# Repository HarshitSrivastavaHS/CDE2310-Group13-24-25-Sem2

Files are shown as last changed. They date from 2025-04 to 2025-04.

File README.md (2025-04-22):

# Autonomous Thermal Search and Rescue Robot

This project presents a custom-built autonomous ground robot designed to simulate a post-earthquake search and rescue scenario. The robot explores an unknown environment using SLAM, identifies potential human survivors based on heat signatures, and marks their locations by deploying a visual flare mechanism (ping pong ball shooter).

The system was developed on the TurtleBot3 Burger platform, integrating mechanical actuation, custom electronics, and a complete ROS2-based navigation and sensing software stack.

---

## 🧩 System Overview

The robot autonomously locates **two heat sources**, simulating trapped humans, and activates a mechanical actuator to launch a flare at each source. It avoids revisiting previously detected targets and explores until both are found.

---

## 🛠 Mechanical Subsystem

A custom **cam-cantilever-spring mechanism** forms the core of the actuator, which launches a ping pong ball upon confirmation of a heat source.

- **Mechanism**: Surface cam, spring-loaded lever, and firing frame  
- **Stroke**: 14 mm  
- **Actuation**: Driven by a motor with gearbox

🔗 Refer to the [`Mechanical/`](./Mechanical/) directory for design files and CAD models.

---

## ⚡ Electrical Subsystem

The electrical architecture is built around a **custom-designed PCB** mounted on the Raspberry Pi, ensuring robust connectivity and easier integration of power and signal lines.

- **Power Supply**: PCB powered via OpenCR 5V output  
- **Components**: Connects thermal sensor, motor driver (L298N), and GPIO-controlled MOSFET  
- **Testing**: JLCPCB performed electrical tests; assembly and validation were done at E2 Electronics Lab  
- **Note**: GPIO pin 24 was intentionally left unused due to a layout issue

📁 All schematics, BOMs, and datasheets are available in the [`Electrical/`](./Electrical/) folder.

---

## 💻 Software Subsystem

The software is implemented using **ROS2 Humble**, running on a Raspberry Pi. It integrates exploration, navigation, thermal detection, and actuator control.

**Key components**:

- **SLAM**: Real-time mapping using `slam_toolbox`  
- **Exploration**: Custom ROS2 node interfacing with the Nav2 stack  
- **Heat Source Detection**: AMG8833 thermal sensor, processed with thresholding  
- **Flare Deployment**: GPIO control of actuator once source is confirmed

📂 Full implementation, test scripts, and configuration are located in the [`Software/`](./Software/) directory.

---

## 👥 Team

- Srivastava Harshit
- Wong Jian Bin
- Singh Siddhant Narayan
- Pranav Vangal Swaminathan
- Ni Hang, Alex

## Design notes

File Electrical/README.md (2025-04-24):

# Electrical

## System Schematics


## the onboard raspberry pi PCB
- To facilitate better wiring and stability of electrical system, the pcb is designed with great help from Mr. Eugene.

### Schematics


#### Bill of material
The bill of material can be found at
<p>
<table>
<tr><td><b>Qty</b></td><td><b>Value</b></td><td><b>Device</b></td><td><b>Footprint Name</b></td><td><b>Parts</b></td><td><b>Detailed Description</b></td><td><b>CATEGORY</b></td><td><b>CREATED_BY</b></td><td><b>DATASHEET</b></td><td><b>DESCRIPTION</b></td><td><b>DIGIKEY_PART_NUMBER</b></td><td><b>DIGI_KEY_PART_NUMBER</b></td><td><b>DRAIN_CURRENT</b></td><td><b>IC_MAX</b></td><td><b>MANUFACTURER</b></td><td><b>MPN</b></td><td><b>OPERATING_TEMPERATURE</b></td><td><b>PACKAGE_SIZE</b></td><td><b>PACKAGE_TYPE</b></td><td><b>PART_STATUS</b></td><td><b>PITCH</b></td><td><b>POPULARITY</b></td><td><b>ROHS</b></td><td><b>SERIES</b></td><td><b>SUBCATEGORY</b></td><td><b>TEMPERATURE_COEFFICIENT</b></td><td><b>THERMALLOSS</b></td><td><b>TOLERANCE</b></td><td><b>TYPE</b></td><td><b>VCEO_MAX</b></td></tr>
<tr><td>2</td><td>10k</td><td>R_AXIAL-7.2MM-PITCH</td><td>RESAD724W46L381D178B</td><td>R6, R8</td><td>Resistor Fixed - Generic</td><td>Resistors</td><td></td><td></td><td>Axial Resistor 7.24 mm pitch 3.81 mm body length 1.78 mm body diameter</td><td></td><td></td><td></td><td></td><td></td><td></td><td></td><td>AXIAL</td><td>THT</td><td></td><td></td><td></td><td></td><td></td><td></td><td></td><td></td><td></td><td></td><td></td></tr>
<tr><td>2</td><td>1N4148DO35-10</td><td>1N4148DO35-10</td><td>DO35-10</td><td>D3, D4</td><td>DIODE</td><td></td><td></td><td></td><td></td><td></td><td></td><td></td><td></td><td></td><td></td><td></td><td></td><td></td><td></td><td></td><td>21</td><td></td><td></td><td></td><td></td><td></td><td></td><td></td><td></td></tr>
<tr><td>2</td><td>1k</td><td>R_AXIAL-7.2MM-PITCH</td><td>RESAD724W46L381D178B</td><td>R5, R7</td><td>Resistor Fixed - Generic</td><td>Resistors</td><td></td><td></td><td>Axial Resistor 7.24 mm pitch 3.81 mm body length 1.78 mm body diameter</td><td></td><td></td><td></td><td></td><td></td><td></td><td></td><td>AXIAL</td><td>THT</td><td></td><td></td><td></td><td></td><td></td><td></td><td></td><td></td><td></td><td></td><td></td></tr>
<tr><td>1</td><td>2828XX-4282834-4</td><td>2828XX-4282834-4</td><td>TERMBLK_254-4N</td><td>5V,12VTERBLK</td><td>4 Position Wire to Board Terminal Block Horizontal with Board</td><td>Fixed Terminal Blocks</td><td></td><td>https://www.te.com/usa-en/product-282834-4.datasheet.pdf</td><td>4 Position Wire to Board Terminal Block Horizontal with Board 0.100" (2.54mm) Through Hole</td><td></td><td></td><td></td><td></td><td>TE Connectivity AMP Connectors</td><td>282834-4</td><td>-40�C ~ 105�C</td><td>NA</td><td>THT</td><td>ACTIVE</td><td>0.100" (2.54mm) </td><td></td><td>COMPLIANT</td><td>Buchanan</td><td>Terminal Blocks</td><td></td><td></td><td></td><td>Through Hole Screw - Rising Cage Clamp Side wire entry Horizontal with Board</td><td></td></tr>
<tr><td>2</td><td>61300211121</td><td>61300211121</td><td>61300211121</td><td>5VSOLENOID, 12VSOLENOID</td><td>CONN HEADER VERT 2POS 2.54MM</td><td></td><td>PCBLayout.com</td><td></td><td></td><td></td><td>732-5315-ND</td><td></td><td></td><td>Wurth Electronics Inc.</td><td>61300211121</td><td></td><td></td><td></td><td></td><td></td><td></td><td></td><td></td><td></td><td></td><td></td><td></td><td></td><td></td></tr>
<tr><td>1</td><td>61300311121</td><td>61300311121</td><td>61300311121</td><td>SERVO</td><td>CONN HEADER VERT 3POS 2.54MM</td><td></td><td>PCBLayout.com</td><td></td><td></td><td></td><td>732-5316-ND</td><td></td><td></td><td>Wurth Electronics Inc.</td><td>61300311121</td><td></td><td></td><td></td><td></td><td></td><td></td><td></td><td></td><td></td><td></td><td></td><td></td><td></td><td></td></tr>
<tr><td>1</td><td>61300511121</td><td>61300511121</td><td>61300511121</td><td>AMG8833</td><td>CONN HEADER VERT 5POS 2.54MM</td><td></td><td>PCBLayout.com</td><td></td><td></td><td></td><td>732-5318-ND</td><td></td><td></td><td>Wurth Electronics Inc.</td><td>61300511121</td><td></td><td></td><td></td><td></td><td></td><td></td><td></td><td></td><td></td><td></td><td></td><td></td><td></td><td></td></tr>
<tr><td>2</td><td>61302011121</td><td>61302011121</td><td>61302011121</td><td>GPIO_EVEN, GPIO_ODD</td><td>CONN HEADER VERT 20POS 2.54MM</td><td></td><td>PCBLayout.com</td><td></td><td></td><td>732-5329-ND</td><td></td><td></td><td></td><td>Wurth Electronics Inc.</td><td>61302011121</td><td></td><td></td><td></td><td></td><td></td><td></td><td></td><td></td><td></td><td></td><td></td><td></td><td></td><td></td></tr>
<tr><td>2</td><td>NMOSFET_TO220</td><td>NMOSFET_TO220</td><td>TO220BV</td><td>Q1, Q2</td><td>N-Channel MOSFET - Generic</td><td>Transistor</td><td></td><td>https://www.diodes.com/assets/Package-Files/TO220-3.pdf</td><td>Generic N Channel MOSFET TO220 Package Through Hole</td><td></td><td></td><td></td><td></td><td></td><td></td><td></td><td>TO220</td><td>THT</td><td></td><td></td><td></td><td></td><td></td><td>MOSFET</td><td></td><td></td><td></td><td>N-Channel</td><td></td></tr>
<tr><td>1</td><td>PINHD-1X2/90</td><td>PINHD-1X2/90</td><td>1X02/90</td><td>JP1</td><td>PIN HEADER</td><td>Headers</td><td></td><td></td><td>Header-Right Angle-2 Position</td><td></td><td></td><td></td><td></td><td></td><td></td><td></td><td></td><td>THT</td><td></td><td>0.100" (2.54mm)</td><td></td><td></td><td></td><td>Headers-Male Pins</td><td></td><td></td><td></td><td>Board to Board or Cable-Unshrouded-Through Hole-Right Angle</td><td></td></tr>
</table>

- Depending on the use case, one may need an extra female 2x20 1.64mm header to act as a connector to Raspberry Pi.

### 3D Model


>[!Note]
>The gerber files can be found at PCB schematic v36_2025-03-21.zip



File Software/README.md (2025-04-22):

# 🧠 Software 

This directory contains all software components used in the robot that autonomously explores an environment, detects thermal heat signatures (simulating trapped humans), and fires a flare to mark the location.

The software runs on **Ubuntu 22.04 (64-bit)** with **ROS2 Humble**, deployed on a **Raspberry Pi 4 (4GB RAM)**.

---

## For more details about a node, kindly go to:
- [`Explorer and Firing/`](./workspace/src/Autonomous-Explorer-and-Mapper-ros2-nav2/)
- [`Thermal/`](./workspace/src/cde2310/)

---

## ⚙️ Setup Instructions

These steps will help you replicate the software environment on a fresh Raspberry Pi setup.

### 1. Clone the Repository

```
git clone https://github.com/<your-username>/CDE2310-Group13-24-25-Sem2.git
cd CDE2310-Group13-24-25-Sem2/Software
```

### 2. Install ROS2 Humble

Follow the official guide for ROS2 Humble on Ubuntu 22.04:  
https://docs.ros.org/en/humble/Installation/Ubuntu-Install-Debians.html

After installing, add ROS to your shell:

```
echo "source /opt/ros/humble/setup.bash" >> ~/.bashrc
source ~/.bashrc
```

### 3. Install Required Libraries

You’ll need the following Python libraries on the Raspberry Pi:

```
pip install adafruit-circuitpython-amg88xx
pip install numpy
```

Also make sure `RPi.GPIO` is available (comes preinstalled on most RPi OSes):

```
sudo apt install python3-rpi.gpio
```

Make sure the following ROS2 packages are installed:

```
sudo apt install ros-humble-navigation2
sudo apt install ros-humble-slam-toolbox
```

### 4. Build the ROS2 Workspace

```
cd workspace
rosdep install --from-paths src --ignore-src -r -y
colcon build
source install/setup.bash
```

---

## 🧪 Nodes Overview

- **thermal.py**  
  Detects heat sources using the AMG8833 sensor and publishes direction commands (`L`, `R`, `F<number>`, `S`) on `/thermal_direction`.

- **explorer.py**  
  Custom frontier-based exploration node. Uses SLAM map to detect unexplored frontiers and plans paths using Nav2 + Dijkstra. Listens to `/thermal` to decide when to stop and fire. Also controls the GPIO pins on the Raspberry Pi to trigger the firing mechanism (flare shooter).

All nodes are written in Python using the `rclpy` client library and structured as standalone ROS2 nodes.

---

## 📂 Folder Structure

- `workspace/` — ROS2 workspace (nodes live in `src/`)
- `test` — Some Test files written during development and testing.
- `images` — Some static image files for the readme

---

## 🧷 Useful Aliases

You can set up these in your `~/.bashrc` to make launching components easier:

```
alias config="cd ~/CDE2310-Group13-24-25-Sem2/Software/workspace/src/cde2310/config"
alias nav2="config && ros2 launch nav2_bringup navigation_launch.py params_file:=./nav2_params.yaml"
alias slam="ros2 launch slam_toolbox online_async_launch.py"
alias thermal="ros2 run cde2310 thermal"
alias explore="ros2 run custom_explorer explorer"
```

---

## 🧯 System Behavior

1. Robot starts SLAM and begins exploring via the `explorer` node.
2. On detecting a heat signature, `thermal` node sends direction codes to `explorer`.
3. `explorer` aligns the robot toward the heat and moves forward until detection is maximized.
4. When the heat is confirmed (`S`), it triggers the launcher using GPIO and marks the location.
5. It then resumes exploration and ignores previously visited heat spots.

---

## 🛠 Testing Notes

Each module was individually tested and passed. However, due to time constraints, final integrated behavior had issues:

- The robot froze during continuous navigation updates when multiple `/thermal_direction` messages were received.
- Arbitration logic between thermal and exploration was insufficient.
- Final demo attempt failed due to lack of smooth integration (our bad 😔).

Future improvements would include using a centralized state machine or ROS2 behavior trees to manage transitions between exploring, detecting, aligning, and firing.

---

## RQT Graph of the setup

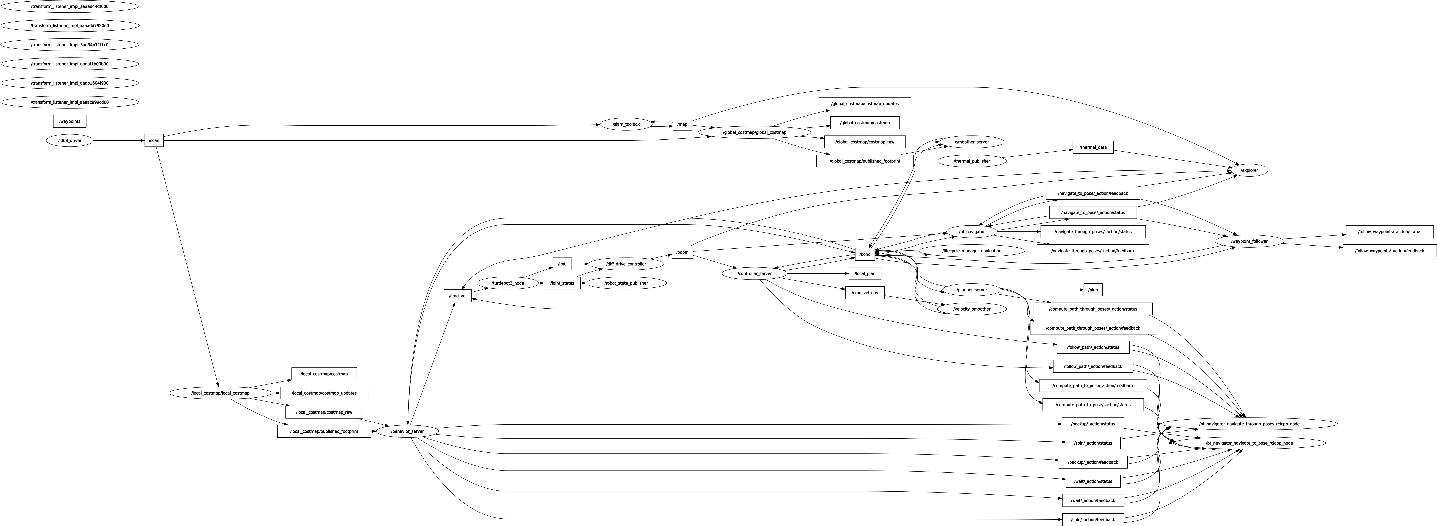
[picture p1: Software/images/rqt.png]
RQT


---

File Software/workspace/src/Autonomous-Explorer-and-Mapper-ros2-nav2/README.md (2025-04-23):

**Explorer Node Overview**

This code implements a ROS2 (Robot Operating System) node that enables a robot to autonomously explore its environment using a thermal sensor (simulated here) and navigate based on detected heat sources. It subscribes to various topics such as the map, odometry, and thermal sensor data, and publishes commands to control the robot's movement.

**Key Functionalities:**

1. **Map and Odometry Handling:**
    - Subscribes to /map for the robot’s environment map (OccupancyGrid).
    - Subscribes to /odom for the robot's current position and orientation (Odometry).
2. **Thermal Sensor Integration:**
    - Subscribes to /thermal_data for thermal sensor readings.
    - Identifies heat sources and makes decisions based on their locations.
3. **Autonomous Navigation:**
    - Uses an action client (NavigateToPose) to navigate to specific positions.
    - Based on thermal data, the robot moves towards detected heat sources, avoids revisiting them, and can perform specific tasks like firing a projectile at heat sources.

**Important Methods:**

**1\. map_callback(msg)**

- **Purpose:** This method receives the environment map (OccupancyGrid) and stores it in the map_data attribute. The map is used later for navigation and exploration.

**2\. odom_callback(msg)**

- **Purpose:** This method processes the robot's position and orientation (odometry data). It extracts the robot's current coordinates and orientation (in radians) using a quaternion-to-Euler conversion.

**3\. thermal_callback(msg)**

- **Purpose:** Receives thermal data from the thermal sensor. The sensor data would be used to identify the location of heat sources. 

**4\. check_heat_source()**

- **Purpose:** This method is periodically triggered by a timer. It checks if a heat source has been detected:
  - If no heat source is detected, it calls self.explore() to continue searching.
  - If a heat source is found, it evaluates the type of action needed based on the heat source's characteristics (e.g., move forward, turn, or fire a projectile).

**5\. startFiring()**

- **Purpose:** This function controls a PWM pin on a Raspberry Pi to simulate firing a flare (a ping pong ball) when a heat source is detected. The firing time is controlled by the PWM_PIN and DUTY_CYCLE parameters.

**6\. move_forward(pixels)**

- **Purpose:** This function computes the target coordinates (target_x, target_y) based on the current robot position and the desired forward distance (calculated from thermal data). It then sends a navigation goal to move the robot towards those coordinates using the NavigateToPose action.

**7\. turn_left_in_place() and turn_right_in_place()**

- **Purpose:** These methods control the robot’s in-place rotation using the cmd_vel topic. The robot turns a specified number of degrees (default 10°) either to the left or right by publishing angular velocity commands.

**Other Key Features:**

- **PWM Control for Firing Mechanism:** The startFiring method demonstrates controlling a firing mechanism via PWM on the Raspberry Pi's GPIO pin. This action is triggered when a specific type of heat source is detected.
- **Exploration and Heat Source Handling:** The robot follows basic rules for detecting and responding to heat sources:
  - If the heat source is a "L" (left turn), it will turn left.
  - If it's "R" (right turn), the robot turns right.
  - If it's "F" (forward), the robot moves forward towards the heat source if it hasn't already visited it.
  - If the heat source is "S" (fire), it activates the firing mechanism.

**Navigation Control:**

- The NavigateToPose action client is used to send movement goals to the robot, either for exploration or for specific heat source targets. These navigation goals are based on the robot’s current position and orientation.

**Dependencies:**

- **ROS2**: This node uses ROS2 for handling topics, actions, and messages (nav_msgs, geometry_msgs, std_msgs, etc.).
- **RPi.GPIO**: For controlling the Raspberry Pi's GPIO pins to manage the firing mechanism.
- **NumPy**: For handling thermal data as arrays.
- **tf_transformations**: For converting quaternion-based orientation data to Euler angles (and vice versa).

---

### The frontier based exploration is forked from a different repo. Credits to the original owner: [AniArka - Autonomous Explorer and Mapper Ros2 Nav2](https://github.com/AniArka/Autonomous-Explorer-and-Mapper-ros2-nav2)

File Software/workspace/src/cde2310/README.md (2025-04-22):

# ThermalPublisher Node

This is a ROS 2 Python node that reads data from the AMG8833 8x8 thermal sensor and publishes directional information based on detected heat patterns.

## Overview

The node captures thermal data and analyzes it to determine the direction of the heat source relative to the sensor. It then publishes a corresponding string message to the `thermal_data` topic.

## Published Topic

- **/thermal_data** (`std_msgs/String`): Contains direction info:
  - `N` – No significant heat source detected
  - `S` – Most pixels are above the threshold (saturation)
  - `L` – Heat is primarily on the left side
  - `R` – Heat is primarily on the right side
  - `F{n}` – Heat is centered; `{n}` indicates number of hot pixels in the center

## How It Works

1. The node initializes the AMG8833 sensor using I2C.
2. It captures thermal data every second.
3. On the **first frame**, the ambient temperature is calculated and saved.
4. In subsequent frames, a dynamic threshold (`ambient + 2.5°C`) is used to identify "hot" pixels.
5. Based on the distribution of hot pixels:
   - If fewer than 5% are hot → `N`
   - If more than 50% are hot → `S`
   - Otherwise, direction (`L`, `R`, `F`) is determined by location of hot spots.

## Dependencies

- ROS 2 (Foxy/Humble or later)
- `adafruit-circuitpython-amg88xx`
- `rclpy`
- `board`
- `busio`
- `std_msgs`

Install the sensor library using pip:
```
pip install adafruit-circuitpython-amg88xx
```

## Running the Node

Make sure your I2C sensor is connected and enabled, then run:
```
thermal
```

> [!CAUTION]
> This assumes you have added an alias by following the instructions [here](../../../README.md).

> [!NOTE]
> Make sure I2C is enabled on your board (e.g., Raspberry Pi).
> The first frame is used to calibrate the ambient temperature.
> If the node starts too close to a heat source, it may skew initial ambient detection.

## Custom parameter file for Nav2 Stack

The custom parameter file for Nav2 Stack is in the config folder.
The file has custom parameters for robot radius, adjusted costmaps settings and other parameters for smoother mission.

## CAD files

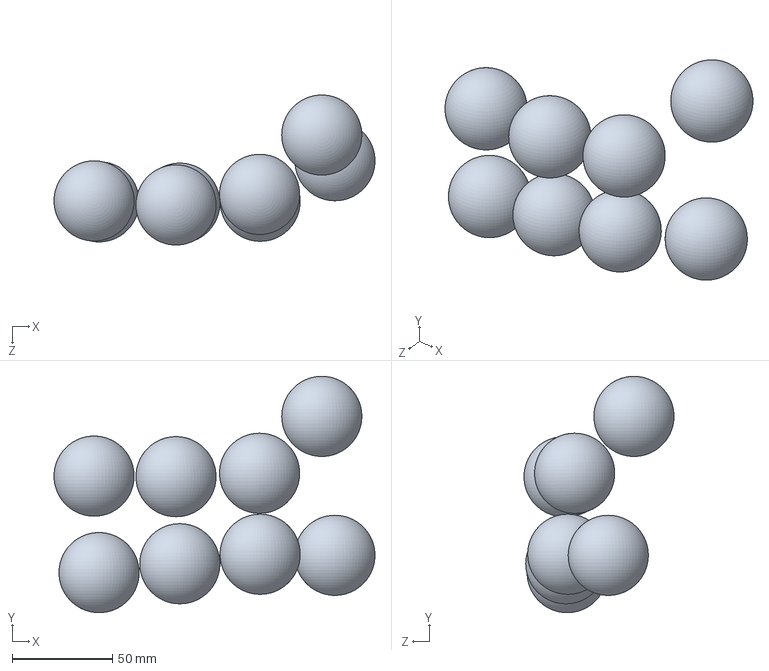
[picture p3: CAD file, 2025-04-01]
Mechanical/Hopper_test.SLDASM
160.2 x 118.0 x 74.9 mm
PingPongBall x 8

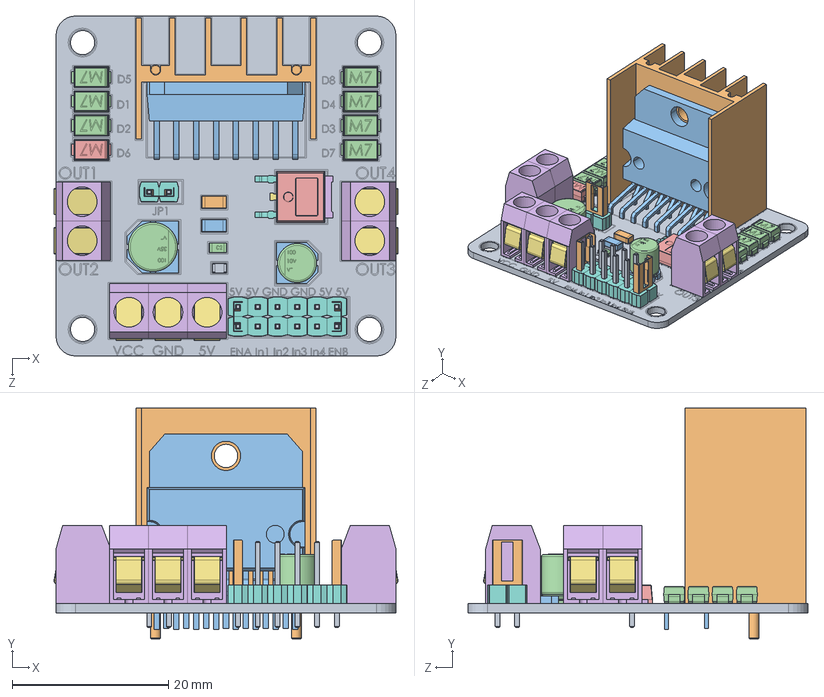
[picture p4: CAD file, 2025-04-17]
Mechanical/Hopper/L298N Motor Driver/L298N Driver.SLDASM
44.0 x 29.5 x 43.5 mm
Board
L298N Heat Sink
L298N
M7 Chip Diode x 7
D5
Left Out Connector x 7
Wire Tension Clip x 7
Spacer x 14
Male Header Pin x 14
Metal Insert x 3
Plastic Base x 2
Cap Body x 2
TO-252_body.stp
TO-252_heatsink_2.stp
TO-252_pin_short.stp
TO-252_pin_standart.stp x 2
LED
Cap 2
Cap 1
Resistor

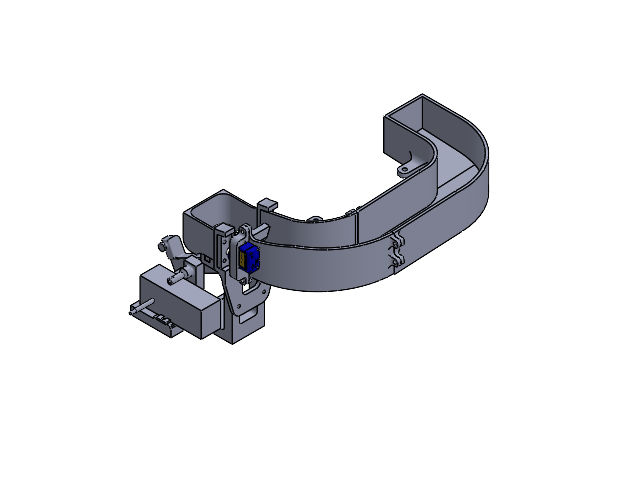
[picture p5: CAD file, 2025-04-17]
Mechanical/Hopper/Hopper_launcher_Assem.SLDASM
mount
cam
lever
pin
Motor
cone_holder
funnel_base
body_v2
pin_funnel
Launcher_mount
Hopper_v2_part1
Hopper_v2_part2

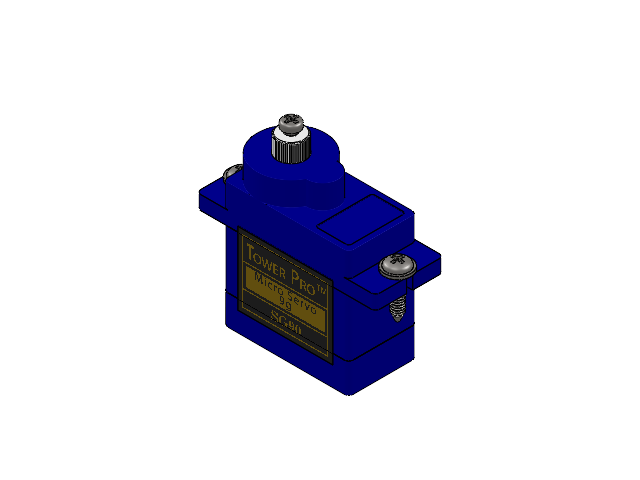
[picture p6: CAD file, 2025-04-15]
Mechanical/Hopper/Micro Servo/SG90 - Micro Servo 9g - Tower Pro.SLDASM
SG90 - Micro Servo 9g - Tower Pro.1
SG90 - Micro Servo 9g - Tower Pro.5 x 2
SG90 - Micro Servo 9g - Tower Pro.6

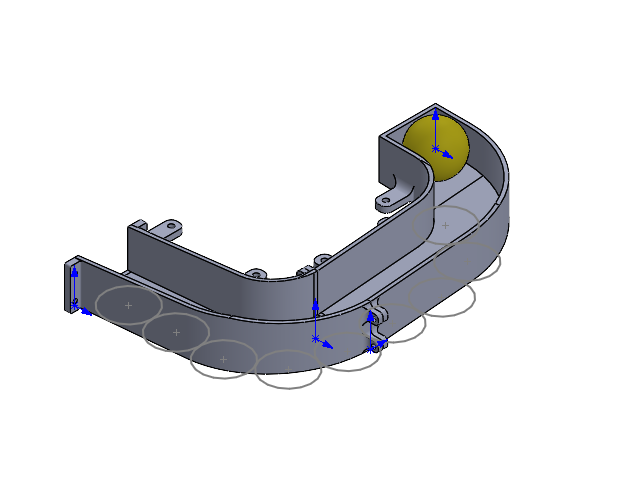
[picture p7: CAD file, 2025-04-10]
Mechanical/Hopper/v1 hopper/v1_Hopper_Assem.SLDASM
Hopper_part1
Hopper_part2

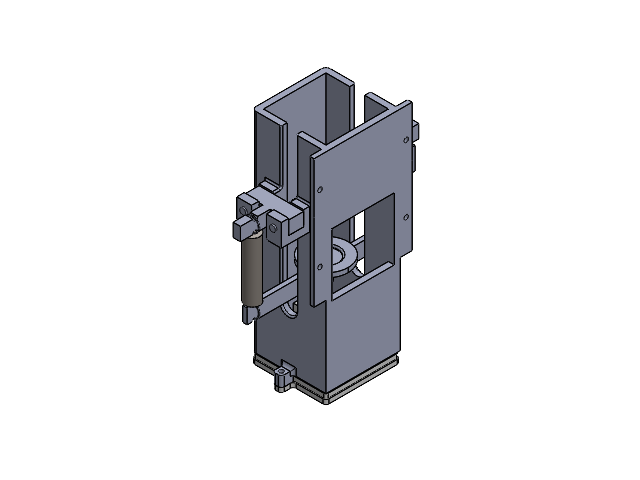
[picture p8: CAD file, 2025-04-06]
Mechanical/Shooter - abandoned/Cannon_Assem_part.SLDASM
Cannon_2
Solenoid_2
plate_2
Spring_rod_2a x 2
Pin_2 x 4
Spring_2 x 2
Solenoid_holder

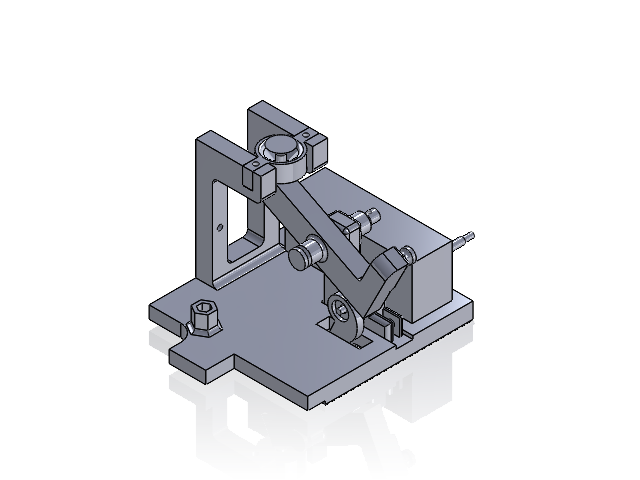
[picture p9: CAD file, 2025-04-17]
Mechanical/shooter - lever/shooter_mech.SLDASM
mount
cam
lever
pin
Motor
cone_holder
funnel_base
body_v2
pin_funnel

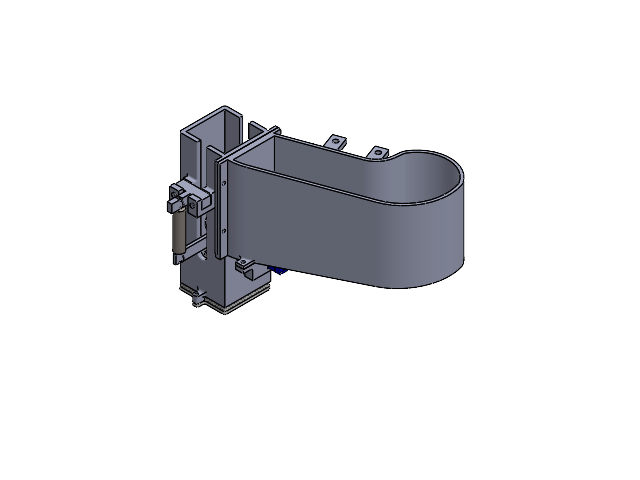
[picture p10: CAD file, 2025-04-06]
Mechanical/Shooter - abandoned/Hopper_cannon_assem.SLDASM
Hopper
Cannon_2
Solenoid_2
plate_2
Spring_rod_2a x 2
Pin_2 x 4
Spring_2 x 2
Solenoid_holder
SG90 - Micro Servo 9g - Tower Pro.1
SG90 - Micro Servo 9g - Tower Pro.5 x 2
SG90 - Micro Servo 9g - Tower Pro.6
SG90 - Micro Servo 9g - Tower Pro.2
Gate
servo_holder

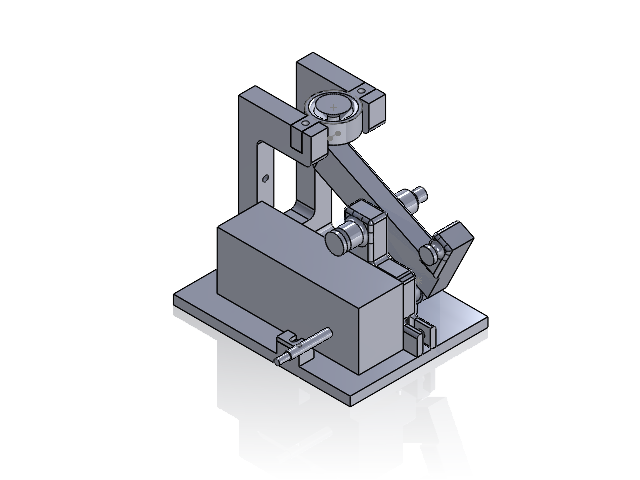
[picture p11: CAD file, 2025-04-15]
Mechanical/shooter - lever/lever_v2/shooter_mech.SLDASM
mount
cam
lever
pin
Motor
cone_holder
funnel_base
body_v2
pin_funnel

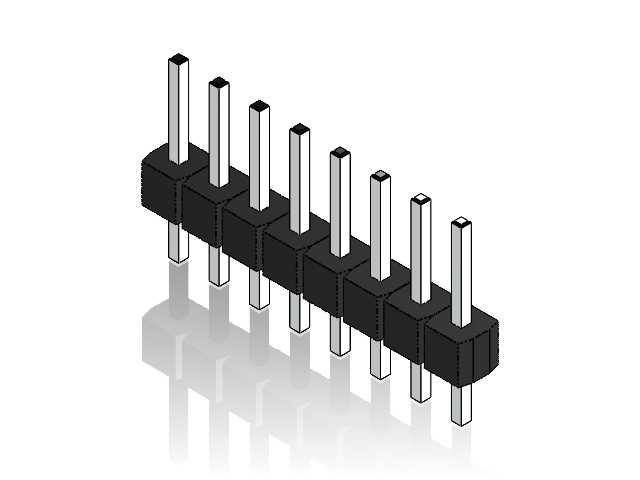
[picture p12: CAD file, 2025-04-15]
Mechanical/Hopper/L298N Motor Driver/JP1.SLDASM
Spacer x 2
Male Header Pin x 2

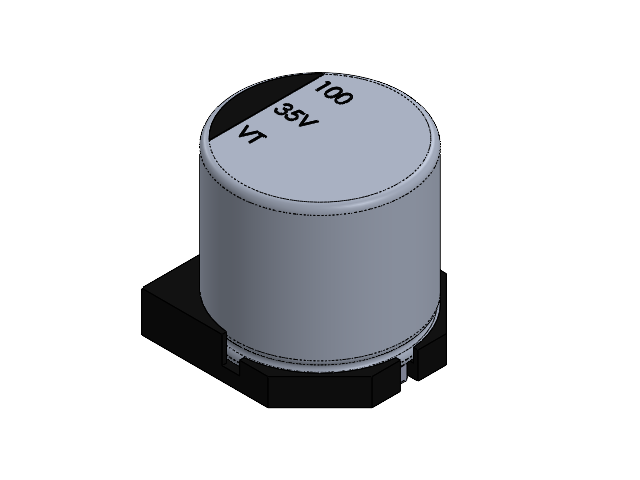
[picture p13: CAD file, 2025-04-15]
Mechanical/Hopper/L298N Motor Driver/Left Cap.SLDASM
Plastic Base
Cap Body

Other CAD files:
Mechanical/Hopper/L298N Motor Driver/Right Out Connector.SLDASM
Mechanical/Shooter - abandoned/Micro Servo/SG90 - Micro Servo 9g - Tower Pro.SLDASM
Mechanical/Hopper/L298N Motor Driver/Left Out Connector.SLDPRT.SLDASM
Mechanical/Hopper/L298N Motor Driver/Voltage Connector.SLDASM
Mechanical/Hopper/L298N Motor Driver/In2 Pin.SLDASM
Mechanical/Hopper/L298N Motor Driver/In3 Pin.SLDASM
Mechanical/Hopper/L298N Motor Driver/In1 Pin.SLDASM
Mechanical/Hopper/.stl files/Cannon_2.STL
Mechanical/Hopper/Cannon_2.SLDPRT
Mechanical/Hopper/Friction_wheel.SLDPRT
Mechanical/Hopper/Friction_wheel_hub.SLDPRT
Mechanical/Hopper/Gate.SLDPRT
Mechanical/Hopper/Hopper_v2_part1.SLDPRT
Mechanical/Hopper/Hopper_v2_part2.SLDPRT
Mechanical/Hopper/L298N Motor Driver/Board.SLDPRT
Mechanical/Hopper/L298N Motor Driver/Cap 1.SLDPRT
Mechanical/Hopper/L298N Motor Driver/Cap 2.SLDPRT
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

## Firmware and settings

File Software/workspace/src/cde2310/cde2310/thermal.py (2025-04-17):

import time
import rclpy
from rclpy.node import Node
from std_msgs.msg import String
import board
import busio
import adafruit_amg88xx

class ThermalPublisher(Node):
    def __init__(self):
        super().__init__('thermal_publisher')
        
        # Initialize I2C bus and sensor
        i2c_bus = busio.I2C(board.SCL, board.SDA)
        self.sensor = adafruit_amg88xx.AMG88XX(i2c_bus)
        
        # ROS Publisher
        self.publisher_ = self.create_publisher(String, 'thermal_data', 10)
        
        self.ambient_initialized = False
        self.ambient_temp = 0.0

        # Timer to publish data every 1 second
        self.timer = self.create_timer(1.0, self.publish_thermal_data)
        
        self.get_logger().info("Thermal Publisher Node Started")

    def publish_thermal_data(self):
        # Analyze the sensor data and decide on direction
        direction = self.analyze_sensor_data()
        
        # Prepare message to be published
        msg = String()
        msg.data = direction
        
        # Publish the message
        self.publisher_.publish(msg)
        self.get_logger().info(f"Published Thermal Data: {msg.data}")

    def analyze_sensor_data(self):
        # Read the sensor data (8x8 array)
        sensor_data = self.sensor.pixels
        self.get_logger().info(f"{sensor_data}")
        # Set threshold for detecting high dots
        flat_data = [pixel for row in sensor_data for pixel in row]

        if not self.ambient_initialized:
            self.ambient_temp = sum(flat_data) / len(flat_data)
            self.ambient_initialized = True
            self.get_logger().info(f"Initial ambient temp set: {self.ambient_temp:.2f}°C")

    
        # Calculate average ambient temperature
        ambient_temp = sum(flat_data) / len(flat_data)
        temp_diff_threshold = 2.5  # Change this value based on how sensitive you want it to be
    
        # Define the dynamic threshold
        threshold = ambient_temp + temp_diff_threshold
        
        # Count the number of pixels above threshold
        above_threshold = sum(1 for row in sensor_data for pixel in row if pixel > threshold)
        
        # Calculate number of high dots on the left, right, and center
        total_pixels = len(sensor_data) * len(sensor_data[0])
        # Check if all are below the threshold
        if above_threshold < 0.05*total_pixels:
            return "N"  # All dots are below threshold
        
        # Check if more than 70% of dots are above threshold
        if above_threshold >= 0.5 * total_pixels:
            return "S"  # More than 70% are above threshold
        
        left_count = sum(1 for row in sensor_data for i in range(4) if row[i] > threshold)  # Left half
        right_count = sum(1 for row in sensor_data for i in range(4, 8) if row[i] > threshold)  # Right half
        center_count = sum(1 for row in sensor_data for i in range(2, 6) if row[i] > threshold)  # Center
        
        # Decide the direction based on high dot positions
        if center_count > left_count and center_count > right_count:
           return f"F{center_count}"
        elif left_count > right_count:
           return "L"
        else:
           return "R"
           
        """
        if left_count > right_count and left_count > center_count:
            return "L"  # More high dots on the left
        elif right_count > left_count and right_count > center_count:
            return "R"  # More high dots on the right
        else:
            return "F"+str(center_count)  # Otherwise, assume it's going straight
        """

def main(args=None):
    rclpy.init(args=args)
    node = ThermalPublisher()
    try:
        rclpy.spin(node)
    except KeyboardInterrupt:
        node.get_logger().info("Shutting down Thermal Publisher")
    finally:
        node.destroy_node()
        rclpy.shutdown()

if __name__ == '__main__':
    main()

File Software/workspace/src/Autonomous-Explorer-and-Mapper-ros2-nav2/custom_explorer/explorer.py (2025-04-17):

import rclpy
from rclpy.node import Node
from nav_msgs.msg import OccupancyGrid
from nav_msgs.msg import Odometry
from geometry_msgs.msg import PoseStamped
from nav2_msgs.action import NavigateToPose
from rclpy.action import ActionClient
from std_msgs.msg import String
import numpy as np
import math
import tf_transformations
import RPi.GPIO as GPIO
import time
from rclpy.duration import Duration
from geometry_msgs.msg import Twist



class ExplorerNode(Node):
    def __init__(self):
        super().__init__('explorer')
        self.get_logger().info("Explorer Node Started")

        # Subscriber to the map topic
        self.map_sub = self.create_subscription(OccupancyGrid, '/map', self.map_callback, 10)
        self.thermal_sub = self.create_subscription(String, '/thermal_data', self.thermal_callback, 10)  #thermal data
        self.odom_sub = self.create_subscription(Odometry, '/odom', self.odom_callback, 10)
        self.current_orientation = None
        # Action client for navigation
        self.nav_to_pose_client = ActionClient(self, NavigateToPose, 'navigate_to_pose')

        # Visited frontiers set
        self.visited_frontiers = set()
        self.visited_heat_sources = []
        
        self.followingHeat = None

        self.current_goal_handle = None
        PWM_PIN = 12  
        GPIO.setmode(GPIO.BCM)
        GPIO.setup(PWM_PIN, GPIO.OUT)
                
        self.heat_source = None  # Latest detected heat location
        self.heat_threshold = 0.5  # Min distance to avoid revisiting (meters)

        # Map and position data
        self.map_data = None
        self.robot_position = (0, 0)  # Placeholder, update from localization

        # Timer for periodic exploration
        self.timer = self.create_timer(5.0, self.check_heat_source)

    def map_callback(self, msg):
        self.map_data = msg
        self.get_logger().info("Map received")

    def odom_callback(self, msg):
        # Extract quaternion from odometry
        position = msg.pose.pose.position
        self.robot_position = (position.x, position.y)

        orientation_q = msg.pose.pose.orientation
        quat = (orientation_q.x, orientation_q.y, orientation_q.z, orientation_q.w)
        roll, pitch, self.current_yaw = tf_transformations.euler_from_quaternion(quat)
        
    def thermal_callback(self, msg):
        """
        Simulated thermal data callback. In real use, this would process AMG8833 data.
        
        thermal_array = np.array(msg.data).reshape((8, 8))  # 8x8 thermal grid
        max_temp = np.max(thermal_array)

        if max_temp > 30:  # Arbitrary threshold for heat detection
            heat_idx = np.unravel_index(np.argmax(thermal_array), thermal_array.shape)
            self.heat_source = heat_idx
            self.get_logger().info(f"Detected heat source at {heat_idx}, Temp={max_temp}")
        else:
            self.heat_source = None
        """
        self.heat_source = msg.data

    def startFiring(self):
        PWM_PIN = 12        # GPIO pin connected to IN1
        DUTY_CYCLE = 14     # 20% duty cycle (approx. 2V if input is 12V)
        FREQUENCY = 1000    # 1 kHz PWM frequency
        TIME = 2.38
        FINAL_TIME = TIME + 0.20



        # Set up PWM
        pwm = GPIO.PWM(PWM_PIN, FREQUENCY)

        pwm.start(DUTY_CYCLE)
        time.sleep(TIME)
        pwm.stop()
        # time.sleep(0.5)
        pwm.start(DUTY_CYCLE)
        time.sleep(TIME)
        pwm.stop()
        time.sleep(4-TIME)
        pwm.start(DUTY_CYCLE)
        time.sleep(FINAL_TIME)
        pwm.stop()

        

    def check_heat_source(self):
        """
        Move in the direction of the detected heat source. If no heat source is detected, explore.
        """
        if self.heat_source is None:
            self.get_logger().info("Heat source is empty.")
            self.explore()
            return


        self.get_logger().info(f"{self.heat_source}")
        if self.map_data is None:
            self.get_logger().warning("No map data available")
            return
        
        if self.heat_source[0] == "N":
            self.get_logger().info("No heat source detected, continuing exploration.")
            self.explore()
            return
            

        match(self.heat_source[0]):
            
            case "L":
                if (self.current_goal_handle):
                    self.current_goal_handle.cancel_goal_async()
                    self.current_goal_handle = None
                self.left_turn()
            case "R":
                if (self.current_goal_handle):
                    self.current_goal_handle.cancel_goal_async()
                    self.current_goal_handle = None
                self.right_turn()
            case "F":
                x, y = self.getCoordinates(self.heat_source[1:])
                result = any(math.sqrt((x - x1)**2 + (y - y1)**2) < 0.15 for (x1, y1) in self.visited_heat_sources) 
                if result:
                    self.get_logger().info("Already visited heat source")
                    self.explore()
                else:
                    if (self.current_goal_handle):
                        self.current_goal_handle.cancel_goal_async()
                        self.current_goal_handle = None
                    self.move_forward(self.heat_source[1:])
                
            case "S":
                """
                FIRE THE PING PONG BALLS
                """
                self.current_goal_handle.cancel_goal_async()
                self.current_goal_handle = None
                self.startFiring()
                self.visited_heat_sources.append(self.robot_position)
            

        """heat_row, heat_col = self.heat_source  # Assuming (row, col) format
            heat_row, heat_col = heat_row - 4, heat_col - 4
            # self.get_logger().info(f"LOL:{heat_col}")
            
            angle_rad = ((heat_col + 4) * (30 / 7) - 30) * 2 * 3.1412 / 360
            w = math.cos(angle_rad / 2)
            z = math.sin(angle_rad / 2)
            
            goal_msg = PoseStamped()
            goal_msg.header.frame_id = 'map'
            goal_msg.header.stamp = self.get_clock().now().to_msg()
            goal_msg.pose.position.x = self.map_data.info.origin.position.x
            goal_msg.pose.position.y = self.map_data.info.origin.position.y
            goal_msg.pose.orientation.w = w
            goal_msg.pose.orientation.z = z
            
            self.get_logger().info(f"{heat_row}, {heat_col}")
            # Wait for the action server
            nav_goal = NavigateToPose.Goal()
            nav_goal.pose = goal_msg

            self.nav_to_pose_client.wait_for_server()
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

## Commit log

2025-03-13 Initial commit
    Added Launcher CAD files and assembly
    [Cannon_2.SLDPRT, Hopper.SLDPRT, Hopper_cannon_assem.SLDASM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]
2025-03-18 Modified hopper
    [Hopper.SLDPRT, Hopper_cannon_assem.SLDASM]
2025-03-18 Added Servo
    [Hopper.SLDPRT, SG90 - Micro Servo 9g - Tower Pro.1.SLDPRT, SG90 - Micro Servo 9g - Tower Pro.2.SLDPRT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]
2025-03-18 Added Gate Servo mount to hopper
    [Hopper.SLDPRT, Hopper_cannon_assem.SLDASM]
2025-03-18 Gate design 1st iteration
    [Gate.SLDPRT, Hopper.SLDPRT, Hopper_cannon_assem.SLDASM]
2025-03-18 Modified gate to allow space for screws/nuts
    [Gate.SLDPRT, Hopper.SLDPRT, Hopper_cannon_assem.SLDASM]
2025-03-20 Modified Hopper mounts
    [Hopper.SLDPRT, Hopper_cannon_assem.SLDASM]
2025-03-20 Cannon assembly file added
    [Cannon_Assem.SLDASM]
2025-03-20 Replaced incorrect files
    Removed incorrect assembly file (Cannon_assem) with Cannon_Assem_part
    [Cannon_Assem.SLDASM, Cannon_Assem_part.SLDASM, Hopper.SLDPRT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]
2025-03-20 Removed temp files
    [Hopper_cannon_assem.SLDASM]
2025-03-24 Add files via upload
    gerber files for pcb v36
2025-03-24 pcb gerber files
2025-03-26 Modified CAD files
    [Hopper_cannon_assem.SLDASM, SG90 - Micro Servo 9g - Tower Pro.SLDASM]
2025-03-27 Update README.md
    added the real image of the pcb
2025-03-27 Update servo.py
    change the pin to be gpio13 acc to pcb
2025-03-27 Update plunger.py
    change the plunger pin to 20 acc to pcb schematics
2025-03-30 Changes to parts to make it stronger
    [Cannon_2.SLDPRT, Cannon_Assem_part.SLDASM, Spring_2.SLDPRT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]
2025-03-30 Modified servo mounting method
    [Hopper.SLDPRT, Hopper_cannon_assem.SLDASM, servo_holder.SLDPRT]
2025-04-01 .stl files and assem changes
    [Cannon_2.SLDPRT, Cannon_2.STL, Cannon_Assem_part.SLDASM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]
2025-04-01 Added sensor holder
    [Cannon_Assem_part.SLDASM, Hopper.SLDPRT, Hopper_cannon_assem.SLDASM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]
2025-04-02 Turtlebot Assem Modifications
    [Hopper_cannon_assem.SLDASM]
2025-04-04 Alternate version for plate_2
    For single spring version
    [plate_2_v2.SLDPRT]
2025-04-05 Friction wheel shooter
    [Cannon_2.SLDPRT, Cannon_2.STL, Gate.SLDPRT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]
2025-04-06 Friction Wheel design changes
    [Friction_wheel_hub.SLDPRT, Hopper_Assem.SLDASM, Hopper_part1.SLDPRT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]
2025-04-06 Mount for hopper
    [Cannon_Assem_part.SLDASM, Hopper_Assem.SLDASM, Hopper_cannon_assem.SLDASM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]
2025-04-07 Added Friction wheel
    [Friction_wheel.SLDPRT, Hopper_Assem.SLDASM, Hopper_part1.SLDPRT]
2025-04-07 new model for launcher
    [Motor.SLDPRT, body.SLDPRT, body_v2.SLDPRT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]
2025-04-07 updated changes to launcher
    Need to work on how to attach this to hopper and turtlebot.
    [body_v2.SLDPRT, cone_holder.SLDPRT, cover.SLDPRT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]
2025-04-08 Added changes to launcher
    [body_v2.SLDPRT, body_v2.STL, cam.SLDPRT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]
2025-04-08 Further changes done to design
    [body_v2.SLDPRT, body_v2.STL, cam.SLDPRT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]
2025-04-09 Hopper v2
    [Hopper_Assem.SLDASM, Hopper_launcher_Assem.SLDASM, Hopper_part1.SLDPRT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]
2025-04-09 added servo holder to v2 hopper
    [Hopper_launcher_Assem.SLDASM, Hopper_v2_part1.SLDPRT, Hopper_v2_part2.SLDPRT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]
2025-04-09 Updated changes to launcher
    [cam.SLDPRT, cam.STL, lever.SLDPRT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]
2025-04-09 Patched servo holder version
    [Hopper_launcher_Assem.SLDASM, servo_holder.SLDPRT]
2025-04-09 Added servo gate
    [Gate.SLDPRT, Hopper_launcher_Assem.SLDASM, Hopper_v2_part1.SLDPRT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]
2025-04-10 Fixed defect in hopper
    [Hopper_launcher_Assem.SLDASM, Hopper_v2_part1.SLDPRT]
2025-04-10 Added turtlebot step file
    [Hopper_launcher_Assem.SLDASM]
2025-04-11 Modified spacers
    [Hopper_launcher_Assem.SLDASM, Hopper_v2_part2.SLDPRT, Spacer.SLDPRT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]
2025-04-13 Updated changes with base support
    [Motor.SLDPRT, body_v2.SLDPRT, cam.SLDPRT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]
2025-04-15 added the l298n motor driver datasheet
2025-04-15 Modified files
    [Motor.SLDPRT, body_v2.SLDPRT, body_v2.STL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]
2025-04-15 Added PCB and Motor Driver to assembly
    [Board.SLDPRT, Cannon_2.SLDPRT, Cannon_2.STL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]
2025-04-16 Added AMG8833 component
    [AMG8833 IR Camera 8x8.SLDPRT, AMG8833 IR Camera 8x8.stp, AMG8833.igs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]
2025-04-16 Added changes for stability
    [cam.SLDPRT, shooter_mech.SLDASM]
2025-04-17 updated explorer and added ambient heat
2025-04-17 Modified launcher parts for increased strength
    [Hopper_launcher_Assem.SLDASM, Left Out Connector.SLDPRT.SLDASM, Right Out Connector.SLDASM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]
2025-04-17 update in yaw
2025-04-17 i'm tired :((
